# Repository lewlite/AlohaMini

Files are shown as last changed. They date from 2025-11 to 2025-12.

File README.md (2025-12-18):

# AlohaMini
 

AlohaMini is a dual-arm mobile robot with a motorized vertical lift — beautifully designed, fully 3D-printable, and affordable.  

Built for embodied AI research and real-world manipulation. Assemble at home in ~60 minutes, customize every part, and train or deploy with LeRobot.

Note:
Use ROS only if you need URDF visualization, RViz inspection, or Gazebo simulation.

## Updates

- [2025-12-18] — URDF and simulation assets are now available for visualization and simulation (`simulation/src/Aloha/`)
- [2025-11-27] STEP (CAD) files are now available (`/hardware/mobile_base/step/`)

### What Makes It Different

- **Motorized vertical lift** — 0–60 cm travel (floor-to-table reach)
- **5-camera perception system** — top, front, back, and dual arm cameras engineered for embodied-AI reproducibility
- **Completely open-source** — hardware and software freely available
- **LeRobot-compatible** — works out of the box
- **Clean, modern design** — built for both function and aesthetics
- **Low-cost & accessible** — engineered so anyone can build a capable robot at home

## 📸 Gallery

<p align="center">
  
</p>

## ⚙️ Bill of Materials (BOM)
### Main Components

| Component | Model / Notes | Qty | Unit Price (USD) |
|---|---|-----|---|
| Servo motors | Feetech STS3215 (12V bus) | 16 | $13.89 |
| Motor control boards | Waveshare Bus Servo Adapter (A) | 2 | $10.55 |
| Compute platform | Raspberry Pi 5 (4/8GB) | 1 | $80 |
| Cameras | 720p USB cameras (2 for arms, 3 for mobile base) | 5 | $20 |
| Mobility system | Omni wheels | 3 | $36.00 |
| Battery | 12V Li-ion pack | 2 | $32.99 |
| Frame | 3D-printed body (ABS / PETG / PLA) | — | ~4kg filament (self-print) |
| **Total** | — | — | **~$600 (self-print)** |

Note: 
- Printable STL files under `/hardware/`
- Compute platform can be replaced with Jetson Nano or similar SBCs if desired.
- URDF files will be released soon

## Quick Start

Start building and running AlohaMini:

1. **Hardware acquisition** — Purchase components and 3D print parts  
   See **[BOM & 3D-Print](docs/BOM.md)**

1. **Assembly** — build the robot in ~60 minutes (SO-ARM pre-assembled)  
   See **[assembly guide](docs/hardware_assembly.md)**

1. **Software setup & teleoperation** — install, connect, and control the robot  
   See **[software guide](docs/software_setup.md)**

##  Product Line
| Model | Build | Rigidity | Target Users |
|---|---|---|---|
| **AlohaMini** | Fully 3D-printed | Standard | Education, makers, research labs, home builds |
| **AlohaMini Pro** | Hybrid **3D-print + metal** | **3×–5× stiffer** | Algorithm-focused researchers who need plug-and-play, reliable, and stable hardware — without assembly effort |

> Same URDF & control stack across both versions — only structural materials differ.

### AlohaMini Pro Access  
Pro hardware & kits available for advanced users.  
📩 **Contact to request early access.**

## Contact
Email: liyiteng+github@gmail.com  
WeChat: liyiteng  
Videos & tutorials soon on: Bilibili / YouTube / TikTok

## Team
AlohaMini is created by:  
**Li Yiteng** / **Wu Zhiyong**

##  Acknowledgements
Thanks to the open robotics community:  
**ALOHA · LeKiwi · SO-ARM100 · SO-ARM100-Track-Axis · Pi-0.5 · LeRobot · Hugging Face**

## ⭐ Support AlohaMini
If you like this project:
- ⭐ Star the repo  
- 🔔 Follow updates  
- 💬 Join the community

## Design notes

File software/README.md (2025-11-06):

This folder includes AlohaMini-specific patches and extensions for the LeRobot framework.

If you prefer a plug-and-play setup with all components already integrated,
please use the dedicated software repository:

👉 https://github.com/liyitenga/lerobot_alohamini

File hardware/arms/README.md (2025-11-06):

The robotic arm used in AlohaMini is a hybrid assembly based on open-source projects.

- Arm base (modified):  
  https://github.com/SIGRobotics-UIUC/LeKiwi/blob/main/3DPrintMeshes/modified_base_arm.stl

- Remaining arm components (SO-101 parts):  
  https://github.com/TheRobotStudio/SO-ARM100/tree/main/STL/SO101

This repository only includes mechanical parts that belong to the AlohaMini main body.

Original SO-101 and LeKiwi files are not redistributed here — please download from upstream.

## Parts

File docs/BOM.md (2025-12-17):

# Bill of Materials

AlohaMini follows the same architecture and terminology as LeKiwi, consisting of a Client side and a Host side.

- The Client handles computation and control.
- The Host executes commands and returns observations.

This is also commonly referred to as PC side vs. Remote side, and both naming conventions are equivalent.

AlohaMini’s Client hardware includes the mobile base and two follower arms. The arms directly reuse the SO-ARM100 design. Therefore, if you already have two SO-ARM100 arms, you only need to assemble the mobile base. Communication between the mobile base, arms, and Raspberry Pi 5 uses the same bus-servo communication system, and the build guide will explain the wiring in detail.

On AlohaMini, the Host side consists of a PC workstation and leader arms. VR controllers or other devices can also replace the leader arms, and we will release compatible controller kits soon. For beginners, we recommend starting with leader-arm teleoperation.

*Note: Table clamp, screwdriver set, soldering iron, and other common tools can be sourced as needed and are not listed in the tables below.*

## Mobile base 

| Item | Model / Notes | Qty | Unit Cost (US) | Buy (US) | Unit Cost (CN) | Buy (CN) |
|---|---|-----|---|---|---|---|
| Servo motor | Feetech / 12V 1/345 Gear(STS3215-C018)| 4 | $13.89 | [Alibaba](https://www.alibaba.com/product-detail/Feetech-12V-1-345-STS3215-C018_1601637205886.html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) | ¥110 | [taobao](https://item.taobao.com/item.htm?id=996544351583&spm=a213gs.v2success.0.0.73c04831naDrHP) |
| Omni wheel | 4″ (≈100 mm) | 3 | $47 | [Amazon](https://www.amazon.com/Replacement-Plastic-Directional-Accessories-Platform/dp/B0F9W6QX5M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) | ¥135 | [pinduoduo](https://mobile.yangkeduo.com/goods.html?ps=kKWPC7xuzw) |
| USB camera | 720p focal length 2.4 mm, 36×36 mm form factor | 3 | — | Amazon | ¥125 | [taobao](https://item.taobao.com/item.htm?id=666278411821) |
| (optional) Bearing | 12×18×4 mm (ID × OD × W) — wheel axle bearing | 3 | — | Amazon | ¥6 | [tmall](https://detail.tmall.com/item.htm?id=824704356695) |
| Bearing | 4×13×5 mm (ID × OD × W) — lift axis bearing | 8 | — | Amazon | ¥3 | [taobao](https://item.taobao.com/item.htm?id=565418362178) |
| M2×12 Phillips screw | For camera mounts (OB_T_Camera_Mount.stl, OB_Top_Camera_Mount) | 12 | — | — | — | — |
| M3×12 hex socket screw | Total 36 pcs (Servo Mount×24 ,Side Panel×12 ) | 36 | — | — | — | — |
| M3×18 hex socket screw | For OB_Chassis_Wheel_Axle_Connector.stl | 12 | — | — | — | — |
| M3×30 hex socket screw | For OB_T_Connector_Right/Left.stl | 8 | — | — | — | — |
| M3 hex nut | For OB_T_Connector_Right/Left.stl | 8 | — | — | — | — |
| M3x5x4 heat-set insert | Total 36 pcs (Servo Mount×24, Side Panel×12) | 36 | — | Amazon | ¥5 | [taobao](https://item.taobao.com/item.htm?id=809241671998) |
| M4×12 hex socket screw | Total 20 pcs (Bearing Cover×12, Z-axis Servo Mount×8) | 20 | — | Amazon | — | — |
| M4x6x5 heat-set insert | For OB_Chassis_Bearing_Cover.stl | 12 | — | Amazon | ¥4 | [taobao](https://item.taobao.com/item.htm?id=809241671998) |
| Adhesive | Epoxy (strongly recommended) / double-sided tape — cable retention & structural bonding | 1 | — | Amazon | ¥12 | [jd](https://item.jd.com/100141557259.html) |
| Servo extension cable | SCS 3-pin, 90 cm | 2 | — | [Alibaba](https://www.alibaba.com/product-detail/3P-5264-Interface-Bus-Actuator-Connection_1601635790774.html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) | ¥3 | [taobao](https://item.taobao.com/item.htm?id=616460581906) |
| Battery | 12 V Li-ion pack with 5521 barrel jack (male & female); one pack for the Raspberry Pi 5, the other for the mobile base and follower arms.| 2 | $43 | [Amazon](https://www.amazon.com/KBT-Rechargeable-Connector-Replacement-Security/dp/B0C242DYT1/ref=sr_1_2_sspa?th=1) | ¥130 | [taobao](https://item.taobao.com/item.htm?id=890828103056) |
| USB Type-C cable | Only for testing the mobile base | 1 | $10 | [Amazon](https://www.amazon.com/Charging-etguuds-Charger-Braided-Compatible/dp/B0B8NWLLW2/?th=1) | ¥20 | [tmall](https://detail.tmall.com/item.htm?id=754024805047) |
| Waveshare Bus Servo Controller | Only for testing the mobile base | 1 | $13 | [Amazon](https://www.amazon.com/Waveshare-Integrates-Control-Circuit-Supports/dp/B0CTMM4LWK/) | ¥27 | [tmall](https://detail.tmall.com/item.htm?id=738817173460) |
| 3D-printed parts | PLA/PETG/ABS (files in /hardware/mobile_base/stl) | ~4 kg filament | — | — | — | — |

**3D Printing Parts List:**
- OB_Chassis_Bearing_Cover x3
- OB_Chassis_Servo_Mount x3
- OB_Chassis_Side_Panel x3
- OB_Chassis_Wheel_Axle_Connector x3
- OB_Chassis_Wheel_Guard x3
- OB_Top_Camera_Back_Cover x2
- OB_Chassis_Shaft_Sleeve_12_24 x3
- O_Chassis_Dowel_Pin_12_37 x3
- All other files x1

Note：
All other parts — including the lift mechanism — can be printed on a standard 3D printer. Only the chassis is special, as it requires a build volume of at least 385 × 345 × 64 mm. We recommend choosing a machine with around 400 × 360 × 100 mm or larger. Due to its size, the chassis may need to be outsourced for printing.

### What the Base Can Do

With only the components above, you can assemble the **mobile base** and control:

- movement  
- vertical lift  

Use the following commands to control the base:
```bash
python examples/debug/wheels.py \
   --port /dev/ttyACM0

python examples/debug/axis.py \
   --port /dev/ttyACM0
```

Use W/S/A/D to drive the base, and U/J to raise or lower the lift — all directly from your PC, without installing any single-board computer on the robot.

More details will be provided in the software setup section.

Effect after assembly:

Assembled AlohaMini mobile base
### Standalone Mode (Optional)

If you prefer the base to operate as an **independent host system** (Wi‑Fi, untethered), add:

| Item | Model / Notes | Qty | Unit Cost (US) | Buy (US) | Unit Cost (CN) | Buy (CN) |
|---|---|-----|---|---|---|---|
| Compute board | Raspberry Pi 5 (4GB/8GB) | 1 | $80 | [Adafruit](https://www.adafruit.com/product/5812) | ¥600 | [taobao](https://item.taobao.com/item.htm?id=688878446695) |
| DC converter | 12V → 5V / 5A buck converter | 1 | $13 | [Amazon](https://www.amazon.com/Klnuoxj-Converter-Interface-Waterproof-Compatible/dp/B0CRVW7N2J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) | ¥75 | [taobao](https://item.taobao.com/item.htm?id=800698078303) |
| Monitor | 7-inch HD IPS HDMI interface + touch + Type C power supply | 1 | — | Amazon | ¥291 | [taobao](https://item.taobao.com/item.htm?id=592070943040) |

## Follower Arms
| Item | Model / Notes | Qty | Unit Cost (US) | Buy (US) | Unit Cost (CN) | Buy (CN) |
|---|---|-----|---|---|---|---|
| Servo motor | Feetech / 12V 1/345 Gear(STS3215-C018) | 12 | $13.89 | [Alibaba](https://www.alibaba.com/product-detail/Feetech-12V-1-345-STS3215-C018_1601637205886.html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) | ¥110 | [taobao](https://item.taobao.com/item.htm?id=996544351583&spm=a213gs.v2success.0.0.73c04831naDrHP) |
| Waveshare Bus Servo Controller | For connecting to the Raspberry Pi 5 | 2 | $13 | [Amazon](amazon.com/Waveshare-Integrates-Control-Circuit-Supports/dp/B0CTMM4LWK/) | ¥27 | [tmall](https://detail.tmall.com/item.htm?id=738817173460) |
| USB camera | 720p focal length 3.8 mm, 32×32 mm form factor | 2 | — | Amazon | ¥103 | [taobao](https://item.taobao.com/item.htm?id=590682120464) |
| 1-to-2 DC splitter cable | 30 cm, 5521 connector — for powering the arms | 1 | — | Amazon | ¥5 | [taobao](https://item.taobao.com/item.htm?id=594921965049) |
| DC extension cable | 1.5 m, 5521 connector — for powering the arms | 2 | — | Amazon | ¥2.50 | [taobao](https://item.taobao.com/item.htm?id=43628177900) |
| USB Type-C cable | For connecting to the Raspberry Pi 5 | 2 | $10 | [Amazon](https://www.amazon.com/Charging-etguuds-Charger-Braided-Compatible/dp/B0B8NWLLW2/?th=1) | ¥20 | [tmall](https://detail.tmall.com/item.htm?id=754024805047) |
| 3D-printed parts | PLA/PETG/ABS (files in /hardware/arms/stl) | 1 set | — | — | — | — |

**3D Printing Parts List:**
- All "D_*.stl" files: x2
- All "F_*.stl" files: x2

For detailed printing instructions, refer to the [SO-ARM100 project README](https://github.com/TheRobotStudio/SO-ARM100)

## Leader Arms
> **Note:** The official SO-ARM100 design uses three different gear ratios (1/147, 1/191, 1/345) for optimal performance. However, our testing shows that using a single gear ratio (1/147) provides excellent user experience and significantly simplifies assembly. The BOM below reflects this simplified configuration.

| Item | Model / Notes | Qty | Unit Cost (US) | Buy (US) | Unit Cost (CN) | Buy (CN) |
|---|---|-----|---|---|---|---|
| Servo motor | Feetech / 7.4V 1/147 Gear(STS3215-C046) | 12 | $13.89 | [Alibaba](https://www.alibaba.com/product-detail/Feetech-STS3215-Servos-Feetech-7-4V_1601636218844.html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) | ¥99 | [taobao](https://item.taobao.com/item.htm?id=996544351583&spm=a213gs.v2success.0.0.73c04831naDrHP) |
| Waveshare Bus Servo Controller | For connecting to the PC | 2 | $13 | [Amazon](https://www.amazon.com/Waveshare-Integrates-Control-Circuit-Supports/dp/B0CTMM4LWK/) | ¥27 | [tmall](https://detail.tmall.com/item.htm?id=738817173460) |
| Battery | 5V Li-ion pack (5600mAh, DC 5521 connector) | 1 | — | Amazon | ¥30 | [taobao](https://item.taobao.com/item.htm?id=765749120668) |
| 1-to-2 DC splitter cable | 70 cm — for powering the arms | 1 | — | Amazon | ¥5 | [taobao](https://item.taobao.com/item.htm?id=594921965049) |
| USB Type-C cable | For connecting to the PC | 2 | $10 | [Amazon](https://www.amazon.com/Charging-etguuds-Charger-Braided-Compatible/dp/B0B8NWLLW2/?th=1) | ¥20 | [tmall](https://detail.tmall.com/item.htm?id=754024805047) |
| 3D-printed parts | PLA/PETG/ABS (files in /hardware/arms/stl) | 1 set | — | — | — | — |

**3D Printing Parts List:**
- All "D_*.stl" files: x2
- All "L_*.stl" files: x2

For detailed printing instructions, refer to the [SO-ARM100 project README](https://github.com/TheRobotStudio/SO-ARM100)

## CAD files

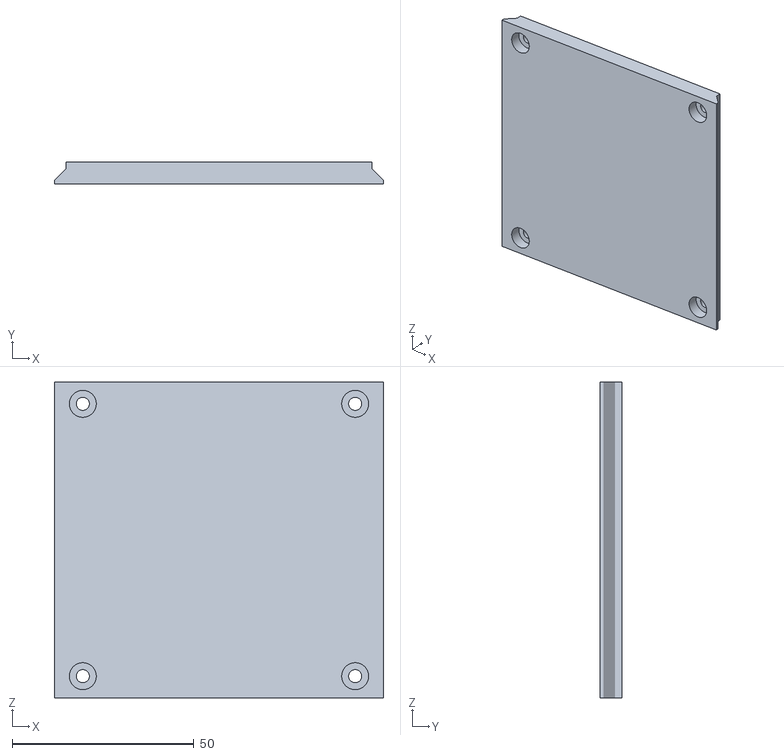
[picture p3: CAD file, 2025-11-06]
hardware/body/stl/OB_Main_Monitor_Connector.stl
90.6 x 6.00 x 87.0

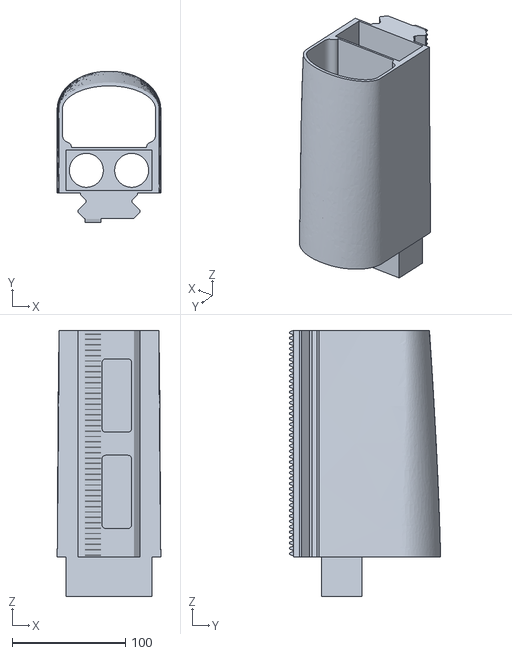
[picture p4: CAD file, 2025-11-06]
hardware/body/stl/O_Main_Assembly_Rod3.stl
91.5 x 133.6 x 235.0

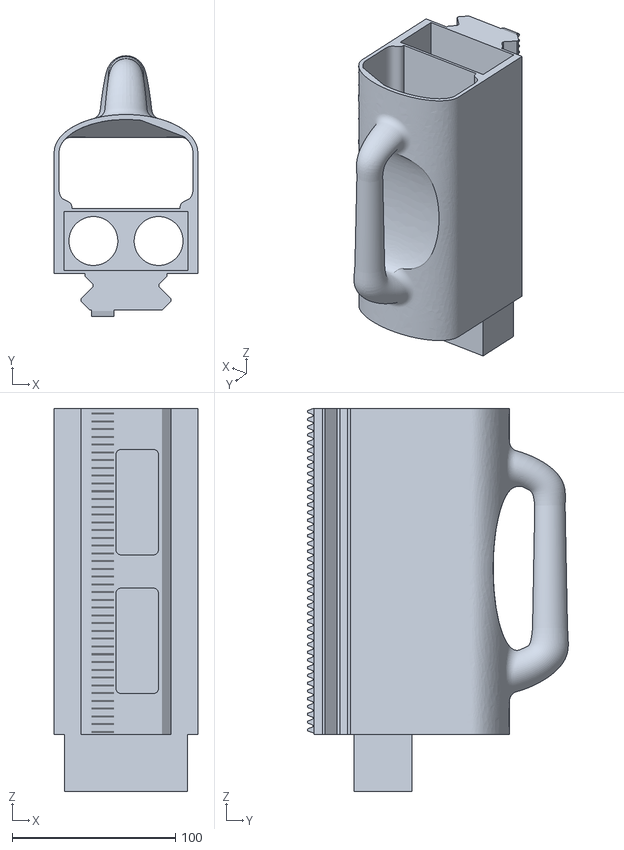
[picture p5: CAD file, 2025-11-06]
hardware/body/stl/O_Main_Assembly_Rod2.stl
88.1 x 159.9 x 235.0

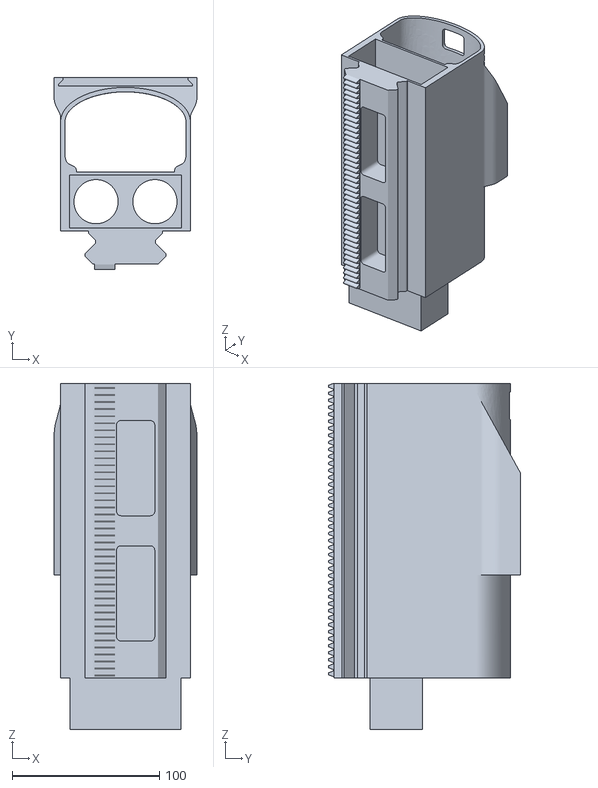
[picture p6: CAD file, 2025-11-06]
hardware/body/stl/O_Main_Assembly_Rod1.stl
97.0 x 130.7 x 235.0

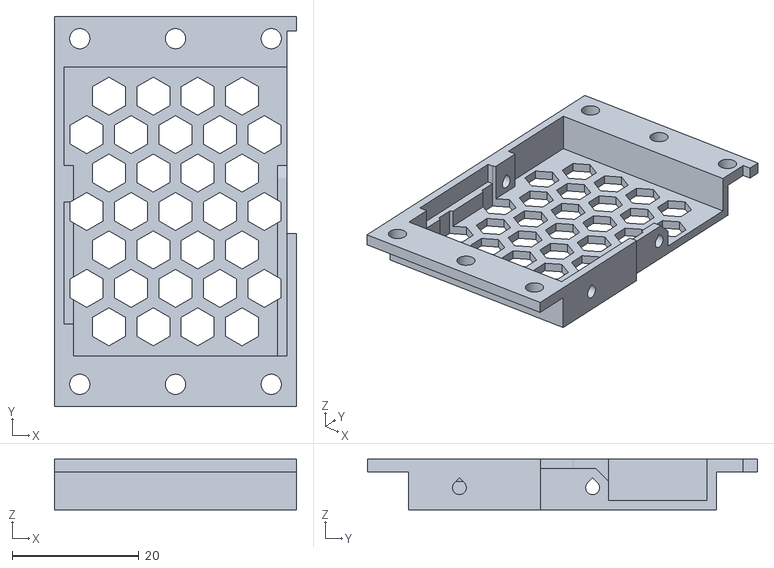
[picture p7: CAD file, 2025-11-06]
hardware/body/stl/OB_Z_Axis_Bracket.stl
38.2 x 61.5 x 8.00

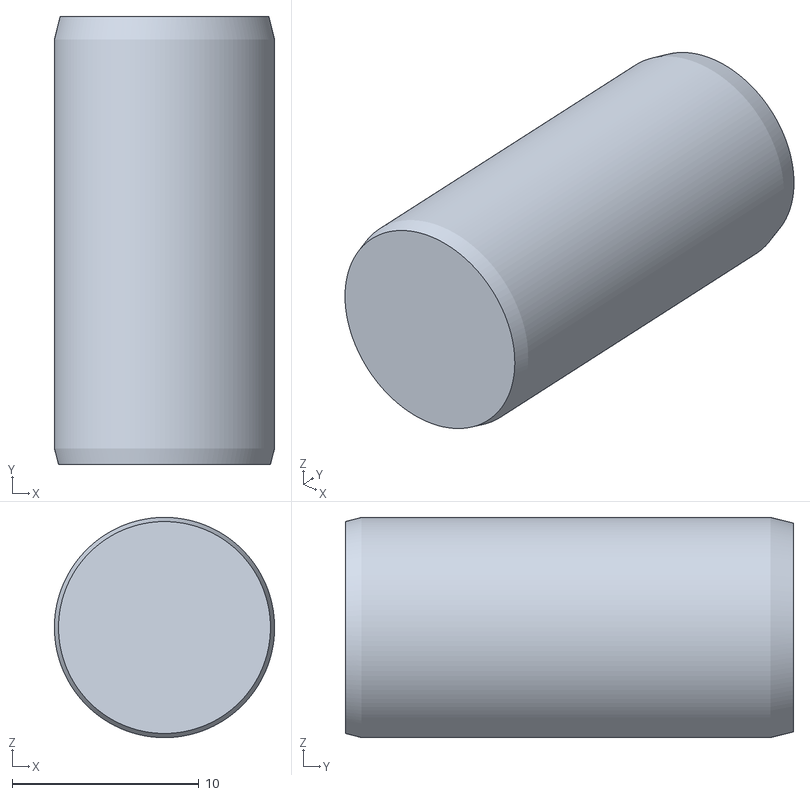
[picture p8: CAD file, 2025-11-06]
hardware/body/stl/Optional/O_Chassis_Dowel_Pin_12_24.stl
11.8 x 24.0 x 11.8

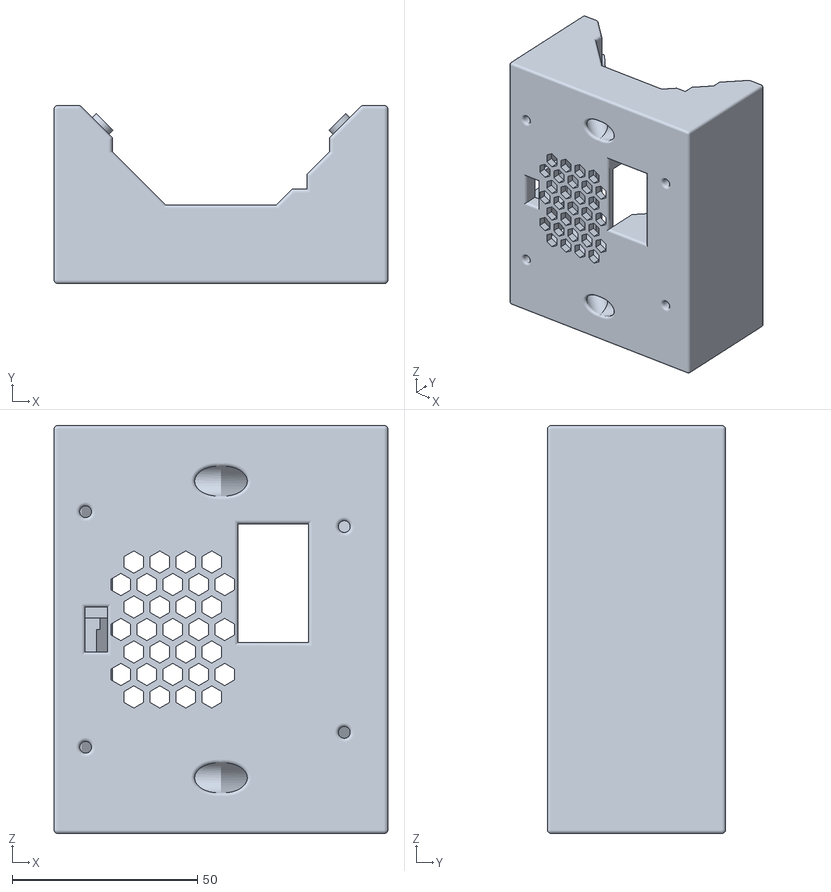
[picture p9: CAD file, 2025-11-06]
hardware/body/stl/OB_Z_Axis_Servo_Mount.stl
90.0 x 48.0 x 110.0

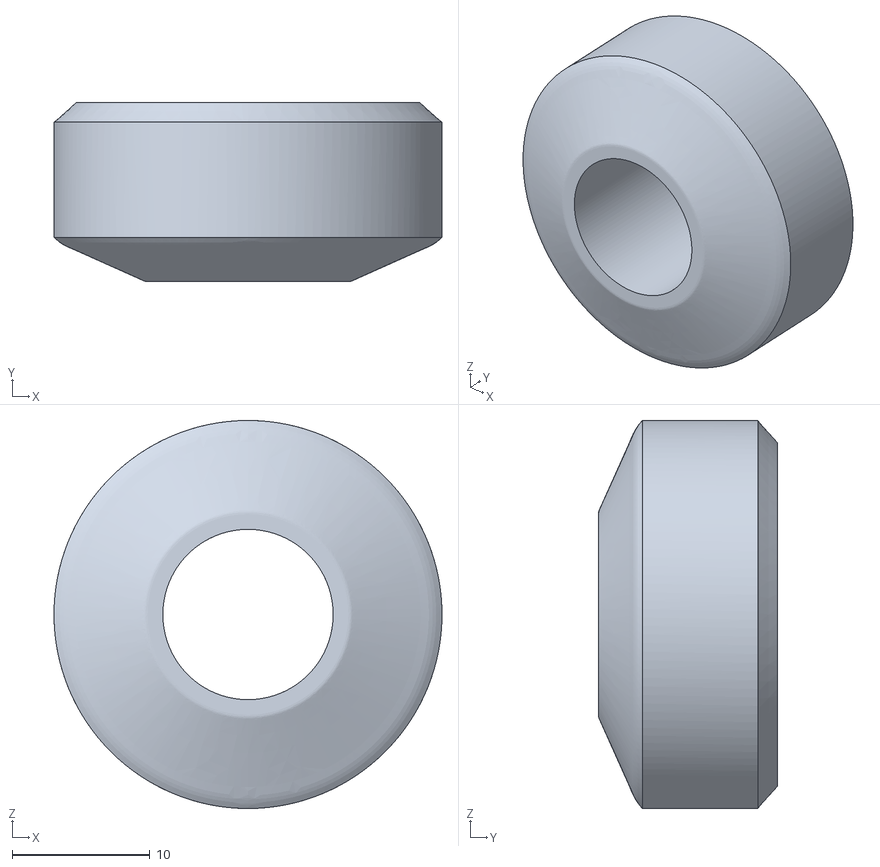
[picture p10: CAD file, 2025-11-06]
hardware/body/stl/Optional/OB_Chassis_Shaft_Sleeve_12_24.stl
28.1 x 13.0 x 28.1

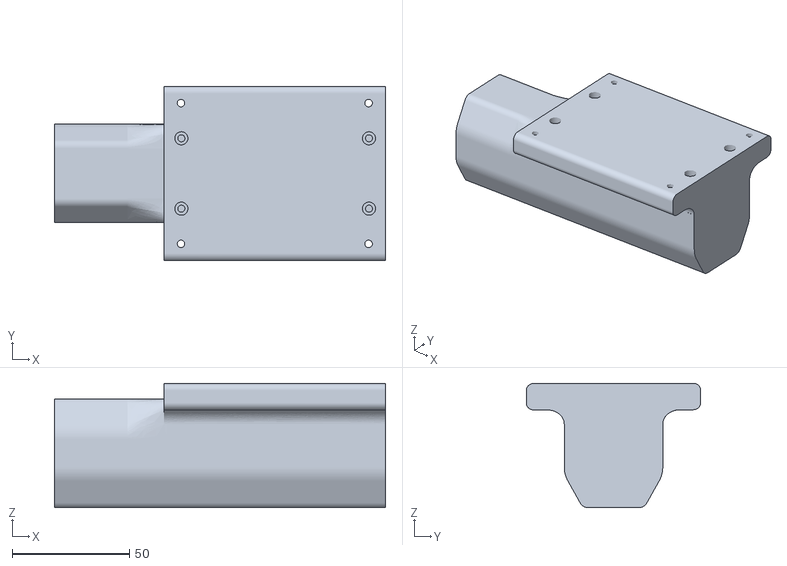
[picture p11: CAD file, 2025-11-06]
hardware/body/stl/OB_T_Connector_Left.stl
141.1 x 74.4 x 53.1

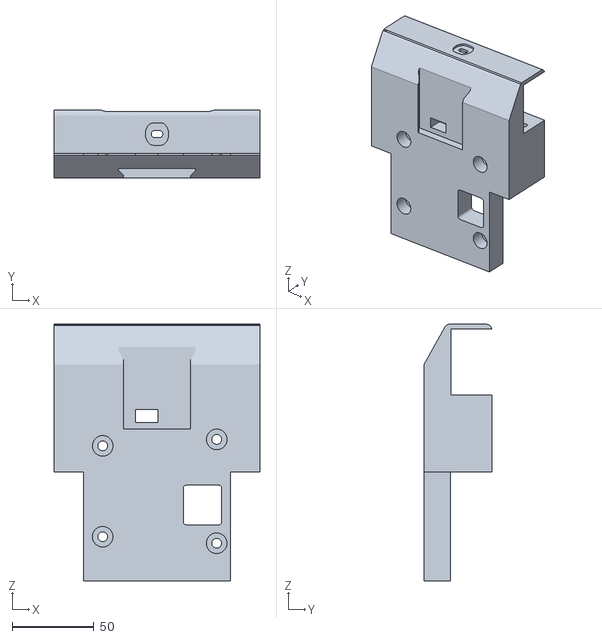
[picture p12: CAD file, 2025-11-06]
hardware/body/stl/OB_T_Connector_Middle.stl
126.0 x 41.6 x 157.2

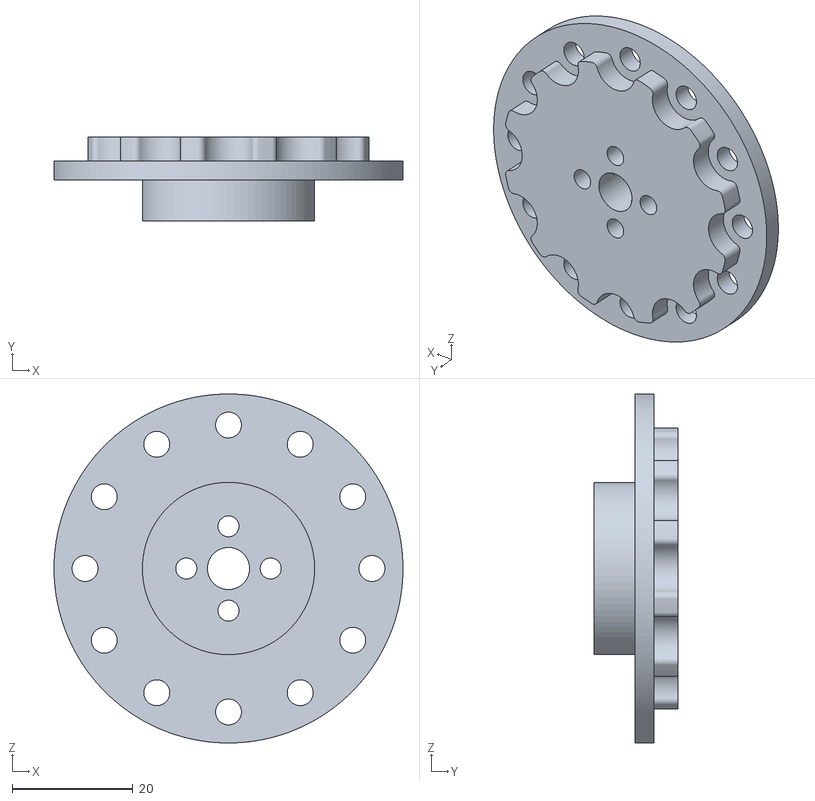
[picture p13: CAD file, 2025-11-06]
hardware/body/stl/OB_Chassis_Wheel_Axle_Connector.stl
57.9 x 14.0 x 57.9

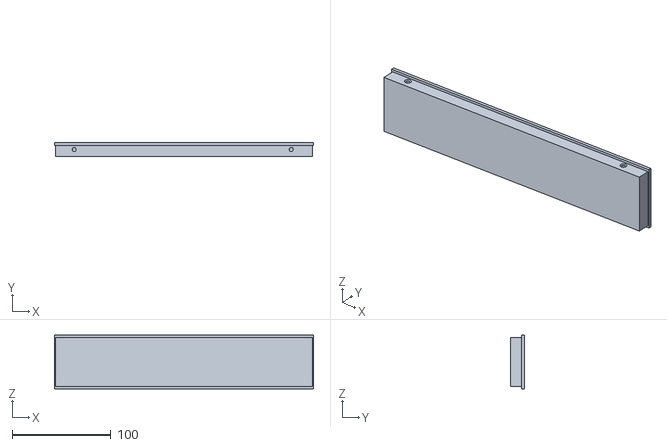
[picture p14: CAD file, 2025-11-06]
hardware/body/stl/OB_Chassis_Side_Panel.stl
262.2 x 14.0 x 54.2

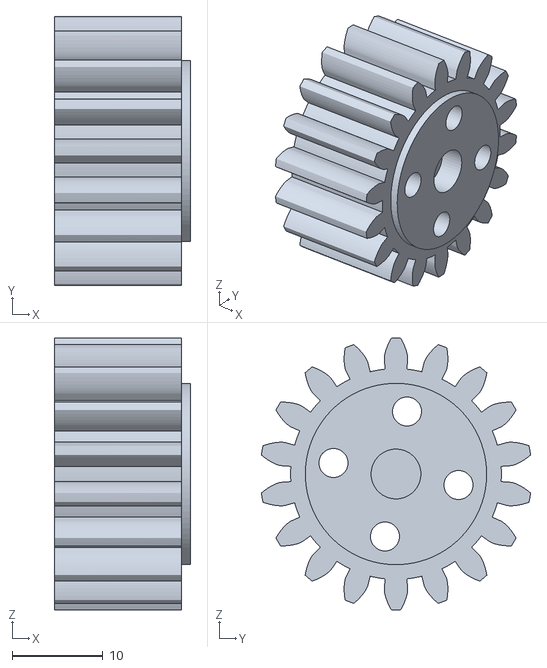
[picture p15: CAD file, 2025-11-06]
hardware/body/stl/OB_Z_Axis_Servo_Gear.stl
15.0 x 29.7 x 30.0

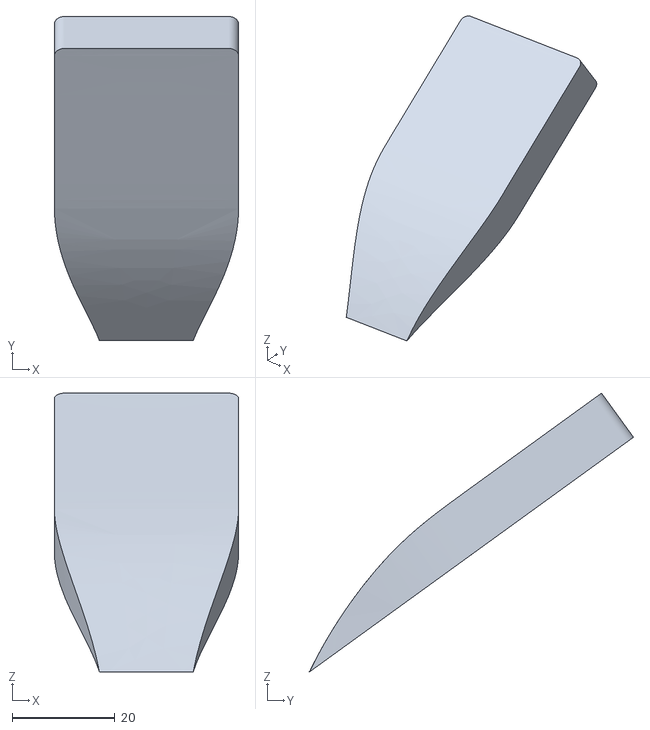
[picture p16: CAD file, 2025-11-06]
hardware/body/stl/OB_Top_Camera_Back_Cover.stl
35.9 x 63.2 x 54.4

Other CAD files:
hardware/body/stl/OB_T_Connector_Right.stl
hardware/body/stl/OB_T_Camera_Mount.stl
hardware/body/stl/O_Chassis_Upper_Plate.stl
hardware/body/stl/OB_Chassis_Servo_Mount.stl
hardware/body/stl/OB_Chassis_Bearing_Cover.stl
hardware/body/stl/O_Chassis_Lower_Plate.stl
hardware/body/stl/O_T_Connector_Cross_Bar.stl

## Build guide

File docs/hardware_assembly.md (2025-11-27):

# Assembly

## Mobile Base Assembly

1. Using the servo software ([FD Debug Tool v1.9.8.3](https://www.feetechrc.com/Data/feetechrc/upload/file/20240622/FD1.9.8.3.zip)), assign ID numbers 8, 9, 10, and 11 to the servos respectively.

   **How to adjust:**
   
   To assign ID numbers to the servos using the FD Debug Tool:
   
   - **Download and install** the FD Debug Tool from the link above
   - **Connect** the servo to your computer using the Waveshare Bus Servo Controller (via USB) 
   - **Launch** the FD Debug Tool software
   - **Select** the correct COM port and set the baud rate (typically 1000000 or as specified in your servo manual)
   - **Click** "Scan Servo" to detect the connected servo and its current ID
   - **Change the ID** by entering the desired number (8, 9, 10, or 11) in the ID field
   - **Click** "Write" or "Save" to update the servo's ID
   - **Disconnect** the servo and repeat the process for each remaining servo
   
   **Note:** Make sure to connect and configure only one servo at a time to avoid ID conflicts during the setup process.

1. Connect servos 8, 9, and 10 using the included 20cm servo cables, and connect servos 10 and 11 using a 90cm servo cable.


3. Install M3 heat-set inserts into the servo brackets using a soldering iron.


4. Secure the servos using the small screws included with the servos.


5. Install the wheel axle connectors.

If the connector doesn't fit, sand it down for a better fit.

Connector installation complete (if it's loose, tighten with screws or use epoxy resin for bonding; no additional treatment needed if it's tight enough).


6. Mount the servos to the chassis plate.

Follow the servo order as shown in the image.


7. Secure the servos to the chassis plate using M3x14 screws.


8. Attach the omni wheels to the servo connector using M3x18 screws.



9.  (optional)Install the chassis bearings.
Insert the bearings (12x18x4) into the dowel pin and shaft sleeves.




10. Install M3 heat-set inserts into the side plates.


11. Assemble the main posts like building blocks - there are 4 in total. Use double-sided tape or epoxy resin to bond the parts together.


12. Install the lift axis. Prepare the materials according to the BOM list.


13. Secure the gear using the screws included with the servo.


14. Insert the gear into the Axis_Servo_Mount.


15. Secure the Axis_Bracket to the servo using the included M3x6 screws from the servo.


17. Install the T-bracket.


18. Secure it with double-sided tape or epoxy resin.




19. Slide the lift axis into the T-bracket.



20. Install the Top and Back cameras.
Remove the two screws from the camera back cover.


21. Reinstall the back cover using M2x12 screws, sandwiching the printed part in between.


22. Route the camera cable through the internal channel of the printed part.


23. Secure the display to the printed part using the included M3 servo screws.


24. Slide the display into the rear slot of the main post.


25. Install the Front camera using the same method as the Top camera.
Slide it into the slot. If there are any burrs on the printed part, file them down for a smooth fit.

26. Route the USB Type-C data cable and DC power cable through the hole on the rear side of the main post.


27. Mobile Base assembly complete!


## Leader arms and Follower arms
For the assembly of Leader arms and Follower arms, please refer to the tutorial: [SO-101 Assembly Guide](https://huggingface.co/docs/lerobot/so101). 

## Follower arms and Mobile Base Assembly

1. Secure the robotic arm to both sides of the T-bracket using four M3x30 hex screws and four M3 nuts.
   

2. Connect the 90cm servo cable from servo #11 to the other port on the Waveshare controller board of the **left arm**.
   

3. Attach the 12V to 5V step-down converter to the base and connect it to the Raspberry Pi.
   

4. Connect the 12V lithium battery to the step-down converter to provide power.
   

5. Connect the male plug of the 1-to-2 DC splitter cable to the female connectors of the two DC extension cables.
   

6. Connect the second 12V lithium battery to the female connector of the 1-to-2 DC splitter cable.
   

7. Assembly fully complete!
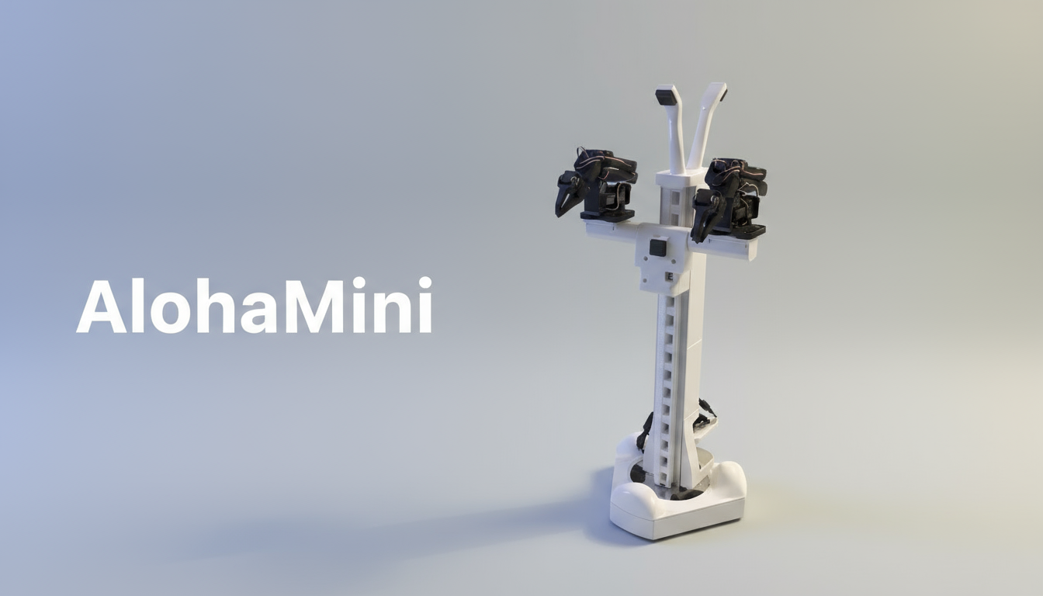
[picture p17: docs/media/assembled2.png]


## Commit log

2025-11-06 add AlohaMini 1.0 beta
    [OB_Chassis_Bearing_Cover.stl, OB_Chassis_Servo_Mount.stl, OB_Chassis_Shaft_Sleeve_12_24.stl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]
2025-11-27 docs: update bom
2025-11-28 feat(cad): add STEP assembly and exploded assembly files
2025-12-03 fix(BOM): correct printed parts filenames for chassis components
2025-12-17 chore(bom): add DC 5521 connector note for battery
